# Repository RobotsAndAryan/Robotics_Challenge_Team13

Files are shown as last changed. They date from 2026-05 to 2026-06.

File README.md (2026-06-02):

# COMP0204 Term 3 Robotics Challenge (2025-2026) 
**Team Number:** 13
**Board ID:** Kayubo

Welcome to our Term 3 robotics project repository! This codebase contains our final firmware for the Trial #2 Checklist. 

For our navigation strategy, we quickly realized that just wandering around until the sensors hit a line wasn't going to work. The arena intersections all look exactly the same to the IR array. Instead, our robot uses a Finite State Machine (FSM) that counts the RFID tags and junctions as it passes them (`base_seq` and `arenaTagCount`). By keeping track of these "nodes", the robot basically knows its coordinates on the map and knows exactly when to turn or switch to dead-reckoning.

---

## Repository Structure
We separated our code into different files to keep the main loop clean and make it easier to debug specific parts of the hardware:

* `main.ino` - The main loop. It checks the network, handles the safety kill switches, and runs the main FSM.
* `config.h` - All our global variables, pin numbers, and PID/Motor speed limits.
* `motion.cpp / .h` - Handles the motor drivers, PWM voltage limits, and our IMU-assisted driving so it drives straight when off the line.
* `sensors.cpp / .h` - Reads the ToF sensor matrix and gets the pitch angle from the IMU.
* `nav.cpp / .h` - Holds the PID line follower logic and the wall-following code.
* `secrets.h` - (Not tracked in git) Contains our WiFi SSID/Passwords and MQTT IPs.
* `/docs` - Folder with Targets to attain, videos of robot's functions working and a report with evidence of sensor logging.
* `/tests` - Old scripts we used to unit-test each component by themselves before integrating them as well.

---

## Required Libraries & Hardware Setup
You'll need these libraries installed to compile our code:
* `Motoron` (Pololu Motoron M3S550 Shield) -> **I2C1**
* `Adafruit MPU6050` (IMU) -> **I2C1**
* `SparkFun VL53L5CX` (Time of Flight Imager) -> **I2C2**
* `MFRC522_I2C` (RFID Scanner) -> **I2C0**
* `Servo` -> **PWM**
* `MiniMessenger` -> **ESP32 WiFi Module**

### Hardware Wiring & Power Notes
* **Power:** We are using a 10.9V battery. To power the Arduino Giga R1 directly so the sensors don't lose power, we soldered a bridge between the `VM` and `AVIN` pins on the Motoron shield. 
* **Voltage Limits:** Our N20 motors are only rated for 6~7V. In `main.ino`, we cap the PWM at `440` (~6V) for normal driving, and bump it up to `514` (~7V) just for the ramp climb so we have enough torque.

---

## How to Run It

1. Clone this repo.
2. Create a `secrets.h` file next to the `.ino` file and put in your WiFi and MQTT credentials.
3. Open `main.ino` in the Arduino IDE (Board: Arduino Giga R1 WiFi) and upload it.
4. **IMU Calibration:** **DO NOT TOUCH THE ROBOT FOR 3 SECONDS AFTER TURNING IT ON.** The MPU6050 takes 200 samples to figure out its zero-bias. If you bump it, the dead-reckoning will curve.
5. **Running the Tasks:**
   * **Tasks 1-6 (Base to Arena):** Turn it on normally. It starts in safe mode. Press the button on `Pin 2` to arm the motors.
   * **Tasks 7 & 8 (Rescue/Obstacle):** Hold down the **Revival Button (Pin 46)** while you power on the board. The code skips the whole base sequence and goes straight into the rescue mode.

---

## System Diagrams & Flowcharts

### 1. Software & Hardware Architecture
We tried to keep the hardware reading separate from the motor writing. The sensors feed data to the control algorithms, which figure out the errors and send them to the FSM. The FSM then tells the motors what to do.

```mermaid
graph TD
    subgraph Hardware Layer
        ToF[VL53L5CX ToF]
        IMU[MPU6050]
        RFID[MFRC522]
        IR[9-Pin IR Array]
        MC[Motoron Controller]
        Srv[Seed Servo]
    end

    subgraph Core Software
        FSM[main.ino FSM Orchestrator]
        Nav[nav.cpp / motion.cpp]
        Net[MiniMessenger / MQTT]
    end

    ToF -->|Clearance Data| FSM
    IMU -->|Pitch Angle| Nav
    IR -->|Sensor Array Values| Nav
    RFID -->|Tag UID| FSM

    FSM <-->|MQTT Messages| Net
    Nav -->|PID Error Updates| FSM
    FSM -->|Motor Speeds| MC
    FSM -->|Servo Angles| Srv
```

### 2. Kill Switch & Emergency Handling
Safety is checked at the very start of the loop before any motor commands are allowed to run.

```mermaid
flowchart TD
    Start((Loop Start)) --> UI[updateUI]
    UI --> HardwareCheck{Pin 2 Pressed?}
    HardwareCheck -->|Yes| ToggleHW[Toggle physical_enable]
    HardwareCheck -->|No| NetCheck[Check MQTT]
    
    NetCheck --> ServerKill{Msg == disable?}
    ServerKill -->|Yes| ToggleNet[wifi_enable = false]
    
    ServerKill -->|No| ServerEmerg{Msg == emergency?}
    ServerEmerg -->|Yes| TriggerExit[Go to STATE_EXIT_SEQUENCE]
    
    ServerEmerg -->|No| Eval{physical & wifi enable = true?}
    
    ToggleHW --> Eval
    ToggleNet --> Eval
    TriggerExit --> Eval
    
    Eval -->|False| Stop[Stop Motors]
    Eval -->|True| FSM[Run Active FSM State]
    
    Stop --> End((Loop End))
    FSM --> End
```

### 3. FSM Routing Sequence (Trial #2)
This shows our exact route through the map, including skipping the first base tag and counting the arena tags to do the 1.25m maneuvers.

```mermaid
stateDiagram-v2
    direction TB
    
    [*] --> BootCheck

    state BootCheck <<choice>>
    BootCheck --> STATE_REVIVE_TARGET : Pin 46 Held
    BootCheck --> STATE_BASE_NAV : Normal Boot

    state STATE_BASE_NAV {
        direction TB
        state "seq=0: Junction 1" as seq0
        state "seq=1: Tag B Scanned" as seq1
        state "seq=2: Right Junction" as seq2
        state "seq=3: Ramp Approach" as seq3

        [*] --> seq0
        seq0 --> seq1 : Detect J1 -> Push & Turn Right (Skip Tag A)
        seq1 --> seq2 : Seed GPS -> Request Airlock A -> Push forward
        seq2 --> seq3 : Detect Right Branch -> Push & Turn Right
        seq3 --> [*] : Pitch < -10.0 deg
    }
    
    STATE_BASE_NAV --> STATE_RAMP_CLIMB

    state STATE_RAMP_CLIMB {
        [*] --> WallFollow
        WallFollow : 514 Speed, 7V Overvolt
        WallFollow --> [*] : Pitch > -5.0 deg
    }
    
    STATE_RAMP_CLIMB --> STATE_ARENA_NAV : Reached Flat Ground

    state STATE_ARENA_NAV {
        direction TB
        state LineFollow : PID Tracking
        state DeadReckon : Open Field Push (Task 4)
        state NodeDecision <<choice>>

        [*] --> LineFollow
        LineFollow --> DeadReckon : lostLineCount > 10
        DeadReckon --> LineFollow : Found Line Again
        LineFollow --> NodeDecision : RFID Tag Scanned
        
        NodeDecision --> LineFollow : tagCount = 1
        NodeDecision --> LineFollow : tagCount = 2 (Turn Right)
        NodeDecision --> LineFollow : tagCount = 3 (Turn Left)
    }

    STATE_ARENA_NAV --> STATE_WAIT_SERVER : Ask Server if Fertile
    STATE_WAIT_SERVER --> STATE_PLANT_SEED : isFertile = True & Seeds < 5
    STATE_WAIT_SERVER --> STATE_ARENA_NAV : isFertile = False OR Out of Seeds
    STATE_PLANT_SEED --> STATE_ARENA_NAV

    STATE_ARENA_NAV --> STATE_EXIT_SEQUENCE : currentXY == (9,3)
    STATE_EXIT_SEQUENCE --> STATE_EXIT_DRIVE : Calculate Turn Angle
    STATE_EXIT_DRIVE --> STATE_DOCKED : Airlock B Open
    STATE_DOCKED --> [*]
```

### 4. RFID Scanning & Planting Logic

```mermaid
flowchart TD
    Scan[readTagUID] --> CheckNew{Is it a new Tag?}
    CheckNew -->|No| Resume[Ignore and Keep Driving]
    CheckNew -->|Yes| Halt[Stop & Save UID]
    
    Halt --> Req[Send isFertile to Server]
    Req --> Wait[STATE_WAIT_SERVER]
    
    Wait --> Resp{Got Reply?}
    Resp -->|Timeout| Resume
    Resp -->|Yes| Fertile{isFertile == true?}
    
    Fertile -->|No| Resume
    Fertile -->|Yes| Plant[STATE_PLANT_SEED]
    
    Plant --> Servo[Move Servo & Wait]
    Servo --> Notify[Send seedPlanted Msg]
    Notify --> Resume
```

---

## Testing, Calibration & Bug Fixes
Getting the logic to match the physical real-world testing took a lot of trial and error. Here is what we calibrated and the main bugs we had to fix:

### Calibration
* **IR Sensor Thresholds:** We found that the ambient light in the lab read around ~400us on the floor and ~800us over the black tape. We set a hard cutoff at `500us` to filter out noise for our center-of-mass math.
* **PID Tuning:** We settled on `Kp = 20.0` and `Kd = 5.0` running at a base PWM of `440`. 
* **ToF Noise:** We had issues with the I2C bus getting overloaded when polling the ToF sensor too fast. We capped the ranging frequency to 60Hz and only read the middle horizontal band of pixels so a single bad reading wouldn't make the robot randomly stop.

### Major Bugs & How We Fixed Them
**1. Double scanning RFID**
* **What happened:** Whenever the motors vibrated over an RFID tag, the tag would bounce slightly out of range of the antenna and back in. The MFRC522 reader thought it was a new tag and would scan it twice in a row. This completely messed up our `arenaTagCount` and made the robot execute its grid turns way too early.
* **The fix:** We added a string comparison check (`strcmp`). We save the UID of the last tag we scanned, and if the "new" tag matches the previous one, the code just returns `false` and ignores it.

**2. Turning Too Early (Kinematic Overshoot)**
* **What happened:** Because our IR array is mounted at the very front of the chassis, it detects the T-Junctions before the wheels actually reach the intersection. When we triggered an immediate 90-degree turn, the robot would pivot off-center and completely lose the track.
* **The fix:** We hardcoded a tiny blind push (`moveForwardTicks(300)`) right before any 90-degree turn. This pulls the wheel axis directly over the center of the line before it pivots.

**3. Line lost in open field**
* **What happened:** If the robot lost the line, our old code would make it spin in place to try and find it again. This meant the robot couldn't handle the Open Field task, because it would just get stuck spinning in circles in the empty space.
* **The fix:** We changed the logic so that if the line is completely lost for more than 10 frames (`lostLineCount > 10`), it totally ignores the PID loop and just pushes straight ahead (`moveStraightDeadReckoning`) using the IMU gyro to keep its heading until it finds the line on the other side.

---

## Trial #2 Checklist
*This validates what our robot can actually do against the COMP0204 grading rubric.*

- [x] **1. Standard Line Tracking:** Smooth PID tracking using the 9-channel array.
- [x] **2. Intersection & Tag Alignment:** Navigates the base junctions, skips Tag B to save time, and stops over Tag A to request the airlock door(for now).
- [x] **3. Solid Grid Navigation:** Executes the exact 1.25m topological maneuver (Node 2 Right -> Node 3 Left) by counting tags.
- [x] **4. Open-Field Dead Reckoning:** Bridges unlined gaps by using the IMU to drive perfectly straight when the line disappears.
- [x] **5. Ramped Incline/Decline Control:** Uses the pitch angle to detect the ramp (`< -10.0` degrees) and increases motor PWM to climb it without stalling.
- [x] **6. Wall Following:** Uses LiDAR distance to keep a 130mm offset from the walls inside the airlocks.
- [x] **7. Obstacle Detection and Avoidance:** ToF sensor detects blocks, stops the robot, and traces a box around the obstacle, returning to its exact original heading.
- [x] **8. Touch-Based Robot Revival:** Uses distance data to smoothly slow down as it gets closer (`map` function from 150mm to 35mm), softly bumps the stranded robot, and reverses back onto the line.

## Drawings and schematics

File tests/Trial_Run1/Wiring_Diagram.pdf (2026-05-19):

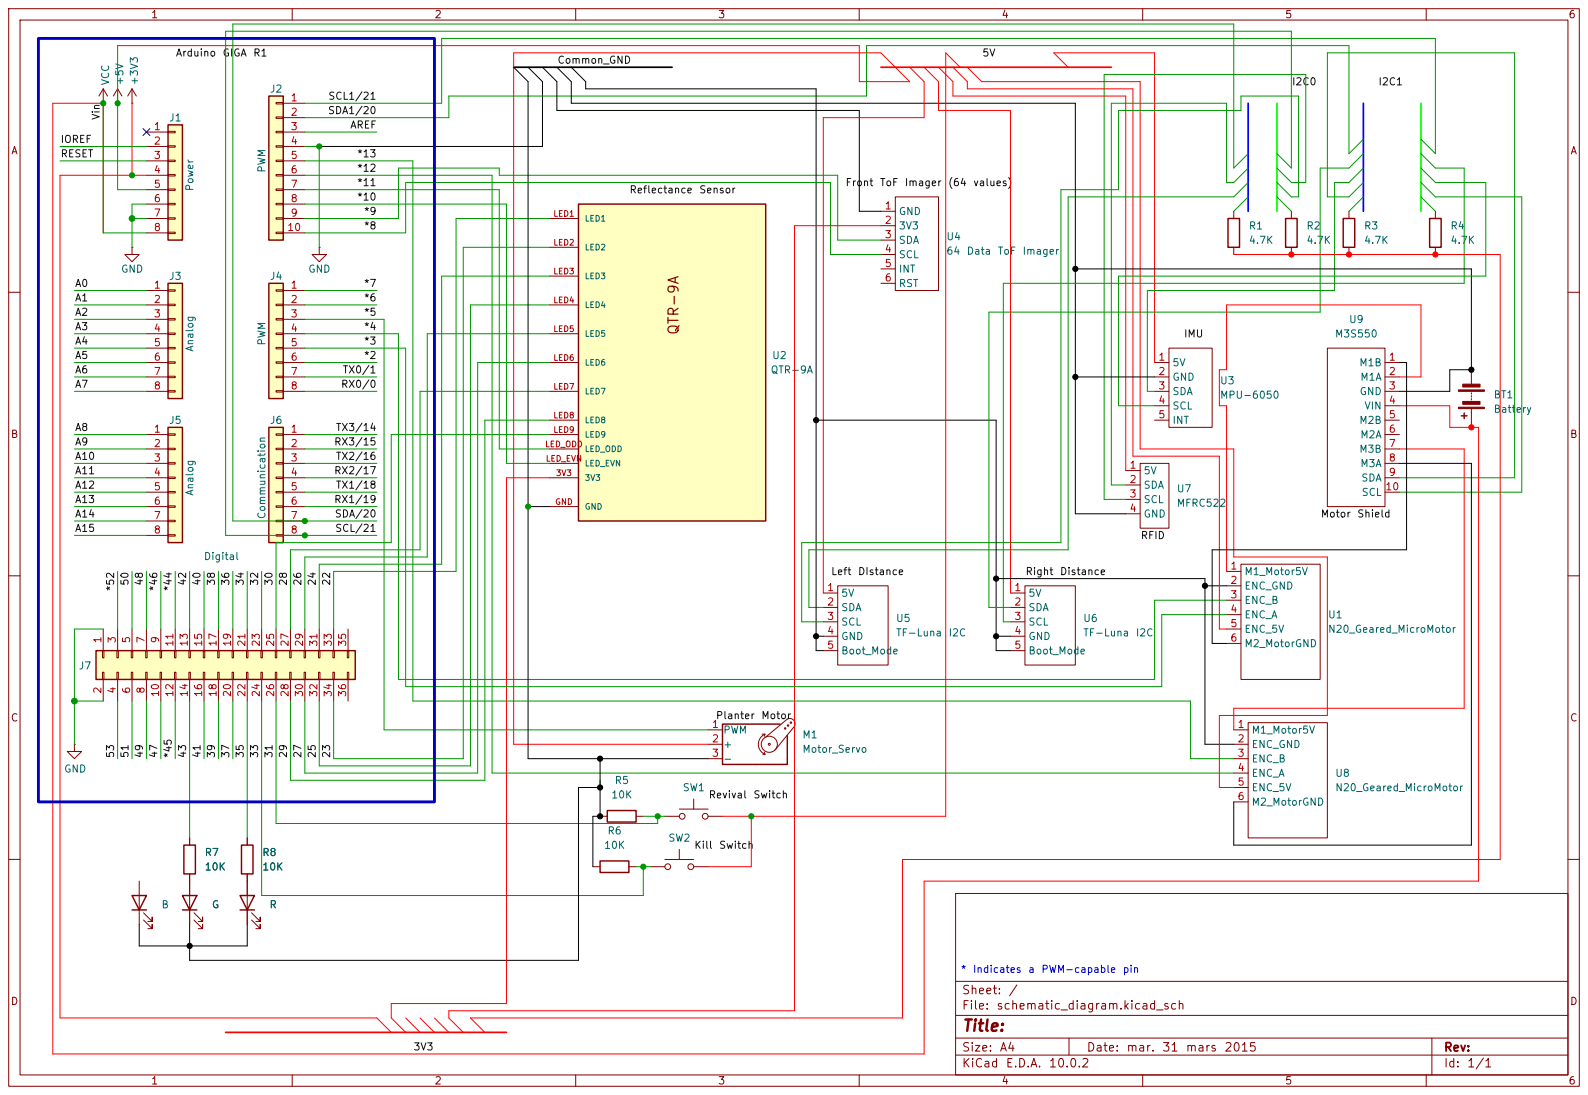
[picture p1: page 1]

SDA 3

64 Data ToF Imager GND LED3 LED3

LED4

Size: A4 | Rev:
KiCad E.D.A. 10.0.2 | Id: 1/1

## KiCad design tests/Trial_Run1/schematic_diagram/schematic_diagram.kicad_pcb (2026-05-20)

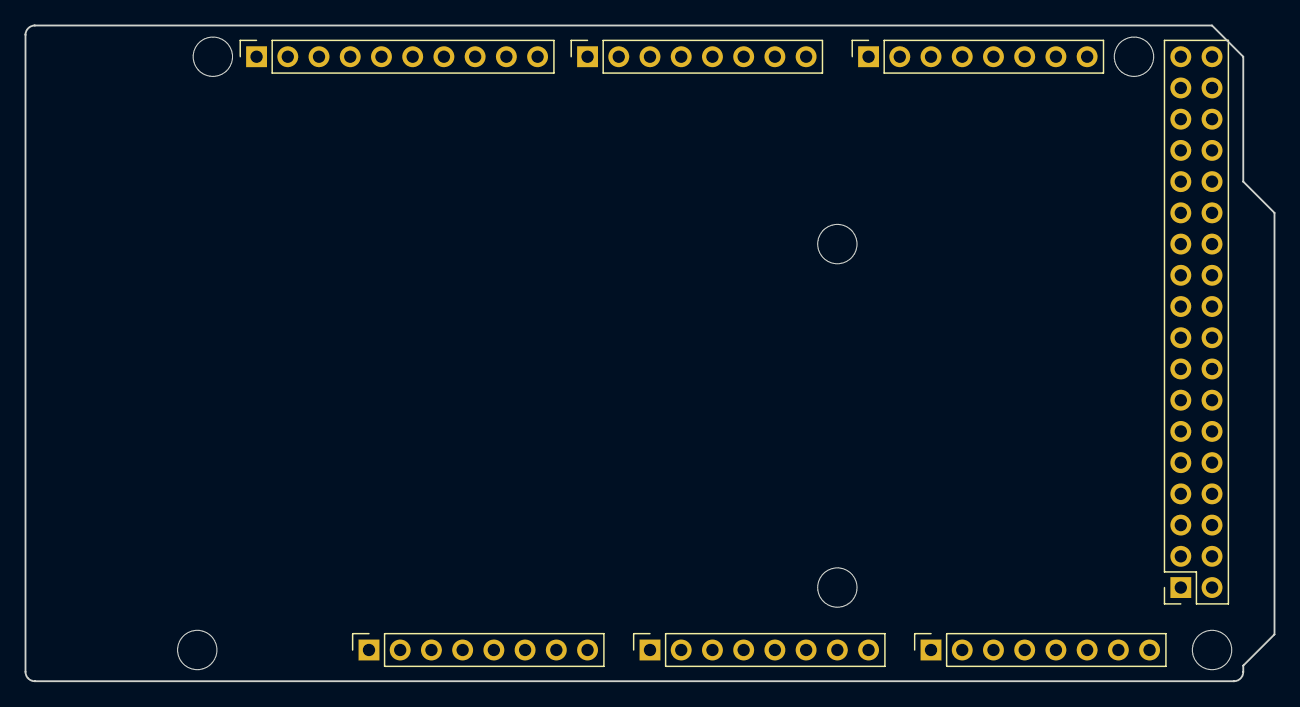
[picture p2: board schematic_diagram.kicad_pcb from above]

Board: 2 copper layers, 101.6 x 53.3 mm, 13 parts (0 on the bottom side), 4 nets, no tracks yet.

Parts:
J1: Power; PinSocket_1x08_P2.54mm_Vertical
J2: PWM; PinSocket_1x10_P2.54mm_Vertical
J3, J5: Analog; PinSocket_1x08_P2.54mm_Vertical
J4: PWM; PinSocket_1x08_P2.54mm_Vertical
J6: Communication; PinSocket_1x08_P2.54mm_Vertical
J7: Digital; PinSocket_2x18_P2.54mm_Vertical
MH1, MH2, MH3, MH4, MH5, MH6: MountingHole_3.2mm

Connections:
+5V: J1.5, J7.35, J7.36
/SCL/21: J2.1, J6.8
/SDA/20: J2.2, J6.7
GND: J1.6, J1.7, J2.4, J7.1, J7.2

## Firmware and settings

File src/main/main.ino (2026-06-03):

#include "config.h"
#include "motion.h"
#include "sensors.h"
#include "nav.h"
#include "secrets.h"

MotoronI2C mc;
Adafruit_MPU6050 imu;
SparkFun_VL53L5CX myToF;
MFRC522_I2C mfrc522(0x28, -1, &Wire); 
Servo seedServo;
MiniMessenger messenger;

const char* BoardId = "Kayubo";
const int LED_PIN = 4;
const int BUTTON_PIN = 2;
const int GREEN_LED_PIN = 3;
const int REVIVAL_BUTTON_PIN = 46;

volatile bool physical_enable = true;   
bool wifi_enable = false;      
bool pathBlocked = false;

volatile bool is_turning = false;

int enc1A = 44; int enc1B = 45;
int enc2A = 39; int enc2B = 40;
volatile long pos1 = 0; volatile long pos2 = 0;

int emitterOdd = 37; int emitterEven = 38;
int linePins[] = {22,23,24,25,26,27,28,29,30};
int weights[] = {40, 30, 20, 10, 0, -10, -20, -30, -40}; 

float Kp_line = 30.0; float Kd_line = 5.0; 
float Kp_wall = 50.0; float wall_target = 5.4; 
float Kp_heading = 30.0;                        
int baseSpeed_6V = 440; int baseSpeed_7V = 590; 
int turning_spd = 600; 
float lastError = 0;
int obstacleThreshold = 100; 
int lostLineCount = 0;
int currentServoAngle = 0;
float z_bias = 0.0;

float dr_targetYaw = 0.0;
float dr_currentYaw = 0.0;
unsigned long dr_lastIMUTime = 0;

RobotState currentState = START_STATE;
RobotState returnState = START_STATE; 
RobotState lastLoggedState = (RobotState)-1; 

unsigned long missionStartTime = 0;
bool missionActive = false;
const unsigned long ABORT_TIME_MS = 90000; 

int base_seq = 0;
int baseTagCount = 0;
int arenaTagCount = 0;
int seedsPlanted = 0;
const int MAX_SEEDS = 5;

bool entryCleared = false;
bool airlockCleared = false;
bool airlockBCleared = false;
bool waitingForServer = false;
bool isFertileZone = false;
unsigned long serverWaitStartTime = 0;
unsigned long flatGroundTime = 0;
char currentTag[32] = "";
char lastScannedTag[32] = ""; 

struct ArenaNode {
  char uid[32];
  int x;
  int y;
  bool known;
};
ArenaNode grid[81];
int currentX = -1;
int currentY = -1;
float globalHeading = 0.0; 

int pitchUpCount = 0;
int pitchDownCount = 0;

char logBuf[128]; 

const char* getStateName(RobotState state) {
  switch(state) {
    case STATE_BASE_NAV: return "BASE_NAV";
    case STATE_RAMP_CLIMB: return "RAMP_CLIMB";
    case STATE_RAMP_DECLINE: return "RAMP_DECLINE";
    case STATE_ARENA_NAV: return "ARENA_NAV";
    case STATE_WAIT_SERVER: return "WAIT_SERVER";
    case STATE_PLANT_SEED: return "PLANT_SEED";
    case STATE_OBSTACLE_AVOID: return "OBSTACLE_AVOID";
    case STATE_REVIVE_TARGET: return "REVIVE_TARGET";
    case STATE_DEAD_RECKONING: return "DEAD_RECKONING";
    case STATE_EXIT_SEQUENCE: return "EXIT_SEQUENCE";
    case STATE_EXIT_DRIVE: return "EXIT_DRIVE";
    case STATE_EXIT_WAIT_SERVER: return "EXIT_WAIT_SERVER";
    case STATE_AIRLOCK_WAIT_B: return "AIRLOCK_WAIT_B";
    case STATE_AIRLOCK_B_DECLINE: return "AIRLOCK_B_DECLINE";
    case STATE_DOCKED: return "DOCKED";
    case STATE_OBSTACLE_STOP : return "OBSTACLE STOPPED";
    default: return "UNKNOWN";
  }
}

void sysLog(const char* message) {
  Serial.println(message);
  if (wifi_enable) {
    messenger.sendToBoard("debug_console", message);
  }
}

void executeTurn(float targetAngle, bool turnLeft) {
  is_turning = true;
  turnAngle(targetAngle, turnLeft);
  is_turning = false;
}

void tick1() { if (digitalRead(enc1A) == digitalRead(enc1B)) pos1++; else pos1--; }
void tick2() { if (digitalRead(enc2A) == digitalRead(enc2B)) pos2++; else pos2--; }

bool robotEnabled() { return physical_enable && wifi_enable; }

bool isRightIntersection() {
  uint16_t lineVals[9];
  for(int i=0; i<9; i++) { pinMode(linePins[i], OUTPUT); digitalWrite(linePins[i], HIGH); }
  delayMicroseconds(15);
  for(int i=0; i<9; i++) { pinMode(linePins[i], INPUT); lineVals[i] = 1000; }
  
  unsigned long st = micros();
  while(micros() - st < 1000) {
    for(int i=0; i<9; i++) {
      if(lineVals[i] == 1000 && digitalRead(linePins[i]) == LOW) lineVals[i] = micros() - st;
    }
  }
  
  bool rightEdge = (lineVals[0] > 500 && lineVals[1] > 500 && lineVals[2] > 500);
  bool centerActive = (lineVals[3] > 500 || lineVals[4] > 500 || lineVals[5] > 500);
  bool leftClear = (lineVals[6] < 500 && lineVals[7] < 500);
  
  return (rightEdge && centerActive && leftClear);
}

bool isLeftIntersection() {
  uint16_t lineVals[9];
  for(int i=0; i<9; i++) { pinMode(linePins[i], OUTPUT); digitalWrite(linePins[i], HIGH); }
  delayMicroseconds(15);
  for(int i=0; i<9; i++) { pinMode(linePins[i], INPUT); lineVals[i] = 1000; }
  
  unsigned long st = micros();
  while(micros() - st < 1000) {
    for(int i=0; i<9; i++) {
      if(lineVals[i] == 1000 && digitalRead(linePins[i]) == LOW) lineVals[i] = micros() - st;
    }
  }
  
  bool leftEdge = (lineVals[6] > 500 && lineVals[7] > 500 && lineVals[8] > 500);
  bool centerActive = (lineVals[3] > 500 || lineVals[4] > 500 || lineVals[5] > 500);
  bool rightClear = (lineVals[0] < 500 && lineVals[1] < 500);
  
  return (leftEdge && centerActive && rightClear);
}

bool isTJunction() {
  uint16_t lineVals[9];
  for(int i=0; i<9; i++) { pinMode(linePins[i], OUTPUT); digitalWrite(linePins[i], HIGH); }
  delayMicroseconds(15);
  for(int i=0; i<9; i++) { pinMode(linePins[i], INPUT); lineVals[i] = 1000; }

  unsigned long st = micros();
  while(micros() - st < 1000) {
    for(int i=0; i<9; i++) {
      if(lineVals[i] == 1000 && digitalRead(linePins[i]) == LOW) lineVals[i] = micros() - st;
    }
  }

  bool leftEdge = (lineVals[6] > 500 && lineVals[7] > 500 && lineVals[8] > 500);
  bool rightEdge = (lineVals[0] > 500 && lineVals[1] > 500 && lineVals[2] > 500);
  bool centerActive = (lineVals[3] > 500 || lineVals[4] > 500 || lineVals[5] > 500);
  
  return (leftEdge && rightEdge && centerActive);
}

bool readTagUID() {
  if (mfrc522.PICC_IsNewCardPresent() && mfrc522.PICC_ReadCardSerial()) {
    char tempTag[32] = "";
    for (byte i = 0; i < mfrc522.uid.size; i++) {
      char hex[4]; snprintf(hex, sizeof(hex), "%02X", mfrc522.uid.uidByte[i]);
      strcat(tempTag, hex);
    }
    mfrc522.PICC_HaltA();

    if (strcmp(tempTag, lastScannedTag) == 0) {
      return false; 
    }
    
    stopMotors();
    strcpy(currentTag, tempTag);
    strcpy(lastScannedTag, currentTag);
    lastError = 0.0;
    lostLineCount = 0;
    
    snprintf(logBuf, sizeof(logBuf), "[RFID] %s", currentTag);
    sysLog(logBuf);
    return true;
  }
  return false;
}

void onMessage(const MessageMetadata& metadata, const uint8_t* payload, size_t length) {
  if (length == 0 || length == 6 || length == 21) return; 
  
  char msg[256];
  if (length >= sizeof(msg)) length = sizeof(msg) - 1;
  memcpy(msg, payload, length);
  msg[length] = '\0';

  if (strstr(msg, "type=heartbeat")) {
    if (strstr(msg, "enable=1") && !wifi_enable) {
      wifi_enable = true;
      sysLog("[NET] ENABLED");
    }
    else if (strstr(msg, "enable=0") && wifi_enable) {
      wifi_enable = false;
      sysLog("[NET] DISABLED");
    }
  }
  
  if (strstr(msg, "type=disable")) {
    wifi_enable = false;
    sysLog("[NET] KILL SWITCH TRIGGERED");
  }

  if (strstr(msg, "type=emergency")) {
    sysLog("[NET] EMERGENCY WARNING - RETURNING TO BASE");
    if (currentState != STATE_EXIT_SEQUENCE && currentState != STATE_EXIT_DRIVE &&
        currentState != STATE_EXIT_WAIT_SERVER && currentState != STATE_AIRLOCK_WAIT_B &&
        currentState != STATE_AIRLOCK_B_DECLINE && currentState != STATE_DOCKED) {
      lastScannedTag[0] = '\0'; 
      currentState = STATE_EXIT_SEQUENCE;
    }
  }
  
  if (currentState == STATE_BASE_NAV && strstr(msg, "entryReply") && strstr(msg, "accepted=true")) {
    entryCleared = true;
  }
  
  if (strstr(msg, "type=openAirlockReply") && strstr(msg, "accepted=true")) {
    if (strstr(msg, "airlock=A")) airlockCleared = true;
    if (strstr(msg, "airlock=B")) airlockBCleared = true;
  }
  
  if ((currentState == STATE_WAIT_SERVER || currentState == STATE_EXIT_WAIT_SERVER) && strstr(msg, "type=isFertileReply")) {
    isFertileZone = strstr(msg, "fertile=true") != nullptr;
    waitingForServer = false;
    
    char* yLoc = strstr(msg, "x=");
    char* xLoc = strstr(msg, "y=");
    if (xLoc && yLoc) {
      currentX = atoi(xLoc + 2);
      currentY = atoi(yLoc + 2);
      snprintf(logBuf, sizeof(logBuf), "[GPS] Updated: (%d, %d)", currentX, currentY);
      sysLog(logBuf);
      
      for(int i=0; i<81; i++) {
        if(!grid[i].known) {
          strcpy(grid[i].uid, currentTag);
          grid[i].x = currentX;
          grid[i].y = currentY;
          grid[i].known = true;
          break;
        } else if (strcmp(grid[i].uid, currentTag) == 0) {
          break;
        }
      }
    }
  }
}

void updateUI() {
  if (!is_turning) {
    messenger.loop();
  }

  static unsigned long lastBtn = 0;
  if (digitalRead(BUTTON_PIN) == LOW && millis() - lastBtn > 300) {
    physical_enable = !physical_enable;
    lastBtn = millis();
    snprintf(logBuf, sizeof(logBuf), "[HW] Switch Toggled: %s", physical_enable ? "ARMED" : "SAFE");
    sysLog(logBuf);
  }

  static unsigned long lastBlink = 0;
  static bool ledOn = false;
  digitalWrite(GREEN_LED_PIN, digitalRead(REVIVAL_BUTTON_PIN) == LOW ? HIGH : LOW);
  if (robotEnabled()) {
    digitalWrite(LED_PIN, HIGH);
  } else {
    if (millis() - lastBlink >= 500) {
      lastBlink = millis();
      ledOn = !ledOn;
      digitalWrite(LED_PIN, ledOn ? HIGH : LOW);
    }
  }

  static unsigned long lastReg = 0;
  if (millis() - lastReg > 3000) {
    char reg[64]; snprintf(reg, sizeof(reg), "type=register team_id=%s board_id=%s", GROUP_ID, BoardId);
    messenger.sendToBoard("server", reg);
    lastReg = millis();
  }
}

void normalizeHeading() {
  while(globalHeading >= 360.0) globalHeading -= 360.0;
  while(globalHeading < 0.0) globalHeading += 360.0;
}

void setup() {
  Serial.begin(115200);
  Wire.begin(); Wire1.begin(); Wire2.begin();

  sysLog("\n[BOOT] Initializing Hardware...");

  pinMode(emitterOdd, OUTPUT); pinMode(emitterEven, OUTPUT);
  digitalWrite(emitterOdd, HIGH); digitalWrite(emitterEven, HIGH);
  pinMode(LED_PIN, OUTPUT); 
  pinMode(BUTTON_PIN, INPUT_PULLUP);
  
  pinMode(GREEN_LED_PIN, OUTPUT); digitalWrite(GREEN_LED_PIN, LOW);
  pinMode(REVIVAL_BUTTON_PIN, INPUT_PULLUP);
  
  pinMode(enc1A, INPUT_PULLUP); pinMode(enc1B, INPUT_PULLUP);
  pinMode(enc2A, INPUT_PULLUP); pinMode(enc2B, INPUT_PULLUP);
  attachInterrupt(digitalPinToInterrupt(enc1A), tick1, CHANGE);
  attachInterrupt(digitalPinToInterrupt(enc2A), tick2, CHANGE);

  seedServo.attach(5); seedServo.write(0);

  mc.setBus(&Wire1); mc.setAddress(0x10);
  mc.reinitialize(); mc.clearResetFlag(); 
  mc.disableCommandTimeout(); 
  mc.setPwmMode(1, 6); mc.setPwmMode(3, 6);
  mfrc522.PCD_Init();

  if (imu.begin(0x68, &Wire1)) {
    imu.setGyroRange(MPU6050_RANGE_1000_DEG);
    float sum = 0;
    for(int i=0; i<100; i++) {
      sensors_event_t a, g, t; imu.getEvent(&a, &g, &t);
      sum += g.gyro.z; delay(2);
    }
    z_bias = sum / 100.0;
  }
  
  if (myToF.begin(0x29, Wire2)) { 
    myToF.setResolution(4 * 4); 
    myToF.setRangingFrequency(60); 
    myToF.startRanging(); 
  }
  
  for(int i=0; i<81; i++) grid[i].known = false;
  randomSeed(analogRead(0));
  messenger.onMessage(onMessage);
  messenger.begin(WIFI_SSID, WIFI_PASSWORD, BROKER_HOST, BROKER_PORT, GROUP_ID, BoardId);

  if (digitalRead(REVIVAL_BUTTON_PIN) == LOW) {
    currentState = STATE_REVIVE_TARGET;
    sysLog("[BOOT] MODE: TASK 8 (REVIVAL)");
  } else {
    currentState = STATE_EXIT_SEQUENCE;
    sysLog("[BOOT] MODE: TASKS 1-6 (FULL SEQUENCE)");
  }
}

void checkGlobalAbort() {
  if (missionActive && millis() - missionStartTime > ABORT_TIME_MS &&
      currentState != STATE_EXIT_SEQUENCE && currentState != STATE_EXIT_DRIVE &&
      currentState != STATE_EXIT_WAIT_SERVER && currentState != STATE_AIRLOCK_WAIT_B &&
      currentState != STATE_AIRLOCK_B_DECLINE && currentState != STATE_DOCKED) {
    sysLog("[MISSION] TIMEOUT. ABORTING.");
    lastScannedTag[0] = '\0';
    currentState = STATE_EXIT_SEQUENCE;
  }
}

void loop() {
  updateUI();

  if (robotEnabled() && !missionActive) {
    missionStartTime = millis();
    missionActive = true;
    sysLog("[MISSION] Timer Started.");
  }

  if (currentState != lastLoggedState) {
    snprintf(logBuf, sizeof(logBuf), "[FSM] %s", getStateName(currentState));
    sysLog(logBuf);
    lastLoggedState = currentState;
  }

  if (!robotEnabled()) { stopMotors(); delay(5); return; }

  checkGlobalAbort();

 // FIX: Explicitly separate the Stop logic (Base) from the Bypass logic (Arena)
  if (currentState == STATE_ARENA_NAV) {
      checkFrontObstacle();
      if (pathBlocked) {
          stopMotors();
          sysLog("[EVENT] Obstacle Detected - Stopping till clear");
          returnState = currentState; 
          currentState = STATE_OBSTACLE_AVOID;
          return;
      }
  } 
  else {
      checkFrontObstacle();
      if (pathBlocked) {
          stopMotors();
          sysLog("[EVENT] Obstacle Detected - Engaging FSM Bypass");
          returnState = currentState; 
          currentState = STATE_OBSTACLE_STOP;
          return;
      }
  }

  float pitch = getPitch();

  switch (currentState) {
    case STATE_BASE_NAV: {
      int navSpeed = (base_seq == 1 || base_seq == 3) ? baseSpeed_6V / 1.1 : baseSpeed_6V;
      int navMax = (base_seq == 1 || base_seq == 3) ? 440 : 500;
      
      if (!executeLineFollow(navSpeed, navMax)) {
        if(++lostLineCount > 25) {
          stopMotors();
          if (base_seq == 3) {
            sysLog("[NAV] Track gap. Pushing blind toward ramp.");
            moveStraightDeadReckoning(300); 
          } else {
            sysLog("[NAV] Track gap recovery push.");
            moveForwardTicks(400); 
          }
          lostLineCount = 0;
        }
      } else {
        lostLineCount = 0;
        long currentDist = (abs(pos1) + abs(pos2)) / 2;
        
        if (base_seq == 0 && currentDist > 500 && isTJunction()) {
          stopMotors();
          sysLog("[NAV] Junc 1: Aligning & Turning Right");
          moveForwardTicks(450); 
          executeTurn(90.0, false);
          base_seq = 1;
          pos1 = 0; pos2 = 0;
        }
        else if (base_seq == 2 && currentDist > 800 && (isTJunction() || isRightIntersection())) {
          stopMotors();
          sysLog("[NAV] Junc 2: Aligning & Turning Right again");
          moveForwardTicks(450); 
          executeTurn(90.0, false); 
          base_seq = 3;
          pos1 = 0; pos2 = 0;
        }
      }

      if (base_seq == 1 && readTagUID()) {
        sysLog("[EVENT] Tag Scanned. Requesting Airlock A.");
        char query[128]; snprintf(query, sizeof(query), "type=openAirlock airlock=A tag_id=%s board_id=%s", currentTag, BoardId);
        messenger.sendToBoard("server", query);
        airlockCleared = false;
        {
          unsigned long airlockWaitStart = millis();
          while(!airlockCleared && millis() - airlockWaitStart < 5000) {
            updateUI(); delay(10);
            if(!robotEnabled()) return;
          }
        }
        sysLog("[NAV] Airlock Open. Pushing through.");
        moveForwardTicks(800);
        base_seq = 2; 
        pos1 = 0; pos2 = 0;
      }

      if (base_seq == 3) {
        if (pitch < -5.0) {
          pitchUpCount++;
          if (pitchUpCount > 5) {
            sysLog("[NAV] Ramp incline confirmed.");
            currentState = STATE_RAMP_CLIMB;
            pitchDownCount = 0;
            flatGroundTime = 0;
          }
        } else {
          pitchUpCount = 0;
        }
      }
      break;
    }

    case STATE_RAMP_CLIMB:
          if (!executeWallFollow(baseSpeed_7V, 800, 1)) {
            setMotors(baseSpeed_7V, baseSpeed_7V, 800); 
          }
          if (abs(pitch) < 5.0) {
            if (flatGroundTime == 0) flatGroundTime = millis();
            else if (millis() - flatGroundTime > 100) {
              sysLog("[NAV] Ramp cleared. Entering Arena.");
              currentState = STATE_ARENA_NAV;
            }
          } else flatGroundTime = 0;
      break;

    case STATE_RAMP_DECLINE:
      if (!executeWallFollow(baseSpeed_6V/1.2, 440, 3)) {
        setMotors(baseSpeed_6V/1.2, baseSpeed_6V/1.2, 440);
      }
      if (abs(pitch) < 5.0) {
        if (flatGroundTime == 0) flatGroundTime = millis();
        else if (millis() - flatGroundTime > 400) {
          currentState = STATE_ARENA_NAV;
        }
      } else flatGroundTime = 0;
      break;

    case STATE_ARENA_NAV: {
      if (!executeLineFollow(baseSpeed_6V, 440)) {
        if(++lostLineCount > 15) {
          stopMotors();
          sysLog("[NAV] Line Lost. Transitioning to FSM Dead Reckoning.");
          dr_targetYaw = globalHeading; 
          dr_currentYaw = globalHeading;
          dr_lastIMUTime = micros();
          currentState = STATE_DEAD_RECKONING;
          lostLineCount = 0;
        }
      } else lostLineCount = 0;

      if (readTagUID()) {
        arenaTagCount++;

        if (arenaTagCount == 1) {
          currentX = 9; currentY = 3;
          snprintf(logBuf, sizeof(logBuf), "[GPS] Entry Node Seeded at (%d, %d)", currentX, currentY);
          sysLog(logBuf);
        }

        waitingForServer = true;
        serverWaitStartTime = millis();
        currentState = STATE_WAIT_SERVER;

        char query[128]; snprintf(query, sizeof(query), "type=isFertile tag_id=%s board_id=%s", currentTag, BoardId);
        messenger.sendToBoard("server", query);

        if (arenaTagCount == 3) {
            sysLog("[NAV] Task 3: Turn Right at Node 3.");
            executeTurn(90.0, false);
            globalHeading -= 90.0;
            normalizeHeading();
        } else if (arenaTagCount == 4) {
            sysLog("[NAV] Task 3: Turn Left at Node 4.");
            executeTurn(90.0, true);
            globalHeading += 90.0;
            normalizeHeading();
        }
      }
      break;
    }

    case STATE_DEAD_RECKONING: {
      sensors_event_t a, g, t;
      imu.getEvent(&a, &g, &t);
      unsigned long now = micros();
      if(dr_lastIMUTime == 0) dr_lastIMUTime = now;
      float dt = (now - dr_lastIMUTime) / 1000000.0;
      dr_lastIMUTime = now;

      float gyroZ = (g.gyro.z - z_bias) * 57.2958;
      if(abs(gyroZ) > 1.0) dr_currentYaw -= gyroZ * dt; 

      float headingError = dr_targetYaw - dr_currentYaw;
      float correction = Kp_heading * headingError;

      setMotors(baseSpeed_6V - correction, baseSpeed_6V + correction, 440);

      if (isLineDetected()) {
        stopMotors();
        sysLog("[NAV] Track re-acquired.");
        dr_lastIMUTime = 0;
        currentState = STATE_ARENA_NAV;
      }
      else if (readTagUID()) {
        stopMotors();
        dr_lastIMUTime = 0;
        arenaTagCount++;
        waitingForServer = true;
        serverWaitStartTime = millis();
        currentState = STATE_WAIT_SERVER;
        
        char query[128]; snprintf(query, sizeof(query), "type=isFertile tag_id=%s board_id=%s", currentTag, BoardId);
        messenger.sendToBoard("server", query);

        if (arenaTagCount == 3) {
            sysLog("[NAV] Task 4: Turn Right at Node 3.");
            executeTurn(90.0, false);
            globalHeading -= 90.0;
            normalizeHeading();
        } else if (arenaTagCount == 4) {
            sysLog("[NAV] Task 4: Turn Left at Node 4.");
            executeTurn(90.0, true);
            globalHeading += 90.0;
            normalizeHeading();
        }
      }
      break;
    }

    case STATE_WAIT_SERVER:
      stopMotors();
      if (!waitingForServer) {
        if (isFertileZone && seedsPlanted < MAX_SEEDS) {
          currentState = STATE_PLANT_SEED;
        } else {
          if (isFertileZone && seedsPlanted >= MAX_SEEDS) sysLog("[WARN] Seeds exhausted. Skipping plant.");
          if (!isLineDetected()) {
            dr_targetYaw = globalHeading;
            dr_currentYaw = globalHeading;
            dr_lastIMUTime = micros();
            currentState = STATE_DEAD_RECKONING;
          } else {
            currentState = STATE_ARENA_NAV;
          }
        }
      } else if (millis() - serverWaitStartTime > 5000) {
        sysLog("[ERROR] Server Timeout.");
        if (!isLineDetected()) {
            dr_targetYaw = globalHeading;
            dr_currentYaw = globalHeading;
            dr_lastIMUTime = micros();
            currentState = STATE_DEAD_RECKONING;
        } else {
            currentState = STATE_ARENA_NAV;
        }
      }
      break;

    case STATE_PLANT_SEED:
      snprintf(logBuf, sizeof(logBuf), "[ACTION] Planting Seed %d/%d.", seedsPlanted + 1, MAX_SEEDS);
      sysLog(logBuf);
      moveForwardTicks(640);
      stopMotors();
      delay(500);
      {
        int targetAngle = currentServoAngle + 45;
        if(targetAngle > 180) targetAngle = 180;
        while(currentServoAngle < targetAngle) {
          currentServoAngle += 2;
          if(currentServoAngle > targetAngle) currentServoAngle = targetAngle;
          seedServo.write(currentServoAngle);
          delay(30);
        }
      }
      for(int d=0; d<10; d++) { delay(100); updateUI(); }
      seedsPlanted++;

      {
        char notify[128]; snprintf(notify, sizeof(notify), "type=seedPlanted tag_id=%s board_id=%s", currentTag, BoardId);
        messenger.sendToBoard("server", notify);
      }
      lastError = 0;
      if (!isLineDetected()) {
          dr_targetYaw = globalHeading;
          dr_currentYaw = globalHeading;
          dr_lastIMUTime = micros();
          currentState = STATE_DEAD_RECKONING;
      } else {
          currentState = STATE_ARENA_NAV;
      }
      break;
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

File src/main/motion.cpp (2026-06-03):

#include "config.h"
#include "motion.h"
#include "sensors.h"
#include "nav.h"
#include <Arduino.h>

void setMotors(int l, int r, int max_pwm) {
  if(l > max_pwm) l = max_pwm;
  if(l < -max_pwm) l = -max_pwm;
  if(r > max_pwm) r = max_pwm;
  if(r < -max_pwm) r = -max_pwm;
  mc.setSpeed(1, -l);
  mc.setSpeed(3, -r);
}

void stopMotors() {
  setMotors(0, 0, 800);
}

void turnAngle(float targetAngle, bool turnLeft) {
  stopMotors();
  unsigned long dStart = millis();
  while(millis() - dStart < 300) { updateUI(); if(!robotEnabled()) return; delay(1); }

  float currentYaw = 0;
  unsigned long lastIMUTime = micros();
  int lSpeed = turnLeft ? -turning_spd : turning_spd;
  int rSpeed = turnLeft ? turning_spd : -turning_spd;

  setMotors(lSpeed, rSpeed, 800);
  float actualTarget = targetAngle - 4.0;
  unsigned long turnStart = millis();

  while(abs(currentYaw) < actualTarget) {
    updateUI(); 
    if(!robotEnabled()) { stopMotors(); return; }
    if(millis() - turnStart > 4000) { break; }

    sensors_event_t a, g, t;
    imu.getEvent(&a, &g, &t);
    unsigned long now = micros();
    float dt = (now - lastIMUTime) / 1000000.0;
    lastIMUTime = now;
    
    float gyroZ = (g.gyro.z - z_bias) * 57.2958;
    if(abs(gyroZ) > 1.0) currentYaw += gyroZ * dt; 
  }

  stopMotors();
  dStart = millis();
  while(millis() - dStart < 300) { updateUI(); if(!robotEnabled()) return; delay(1); }
  lastError = 0;
}

void moveForwardTicks(long targetTicks) {
  pos1 = 0; pos2 = 0;
  unsigned long moveStart = millis();
  setMotors(baseSpeed_6V, baseSpeed_6V, 440);
  while(abs(pos1) < targetTicks && abs(pos2) < targetTicks) {
    updateUI();
    if(!robotEnabled()) { stopMotors(); return; }
    if(millis() - moveStart > 5000) { break; }
    delay(1);
  }
  stopMotors();
}

void moveStraightDeadReckoning(long targetTicks) {
  pos1 = 0; pos2 = 0;
  float currentYaw = 0;
  unsigned long lastIMUTime = micros();
  unsigned long moveStart = millis();

  while(abs(pos1) < targetTicks && abs(pos2) < targetTicks) {
    updateUI();
    if(!robotEnabled()) { stopMotors(); return; }
    if(millis() - moveStart > 5000) { break; }

    checkFrontObstacle();
    if(pathBlocked) { stopMotors(); return; }

    sensors_event_t a, g, t;
    imu.getEvent(&a, &g, &t);
    unsigned long now = micros();
    float dt = (now - lastIMUTime) / 1000000.0;
    lastIMUTime = now;

    float gyroZ = (g.gyro.z - z_bias) * 57.2958;
    if(abs(gyroZ) > 1.0) currentYaw -= gyroZ * dt;

    float headingError = 0.0 - currentYaw;
    float correction = Kp_heading * headingError;

    setMotors(baseSpeed_6V - correction, baseSpeed_6V + correction, 440);
    delay(2);
  }
  stopMotors();
}

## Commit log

2026-04-28 correcting IR test code
    [reflectance.ino]
2026-05-05 Tested the Wall Lidar
2026-05-06 IMU sensor code working
2026-05-06 PID in Line Following
2026-05-09 motor testing code added
2026-05-09 Added wiring details on the newly created first main code
2026-05-13 Trial Run 1 Code
    [schematic_diagram.kicad_pcb, schematic_diagram.kicad_sch]
2026-05-14 Fixed? Trial Run 1 Code
    [Trial_Run_Code.ino]
2026-05-19 Create ArduinoComms
2026-05-19 working code
    [schematic_diagram.kicad_sch]
2026-05-19 Add files via upload
    Kill switch code so far
2026-05-20 new Line Following and front object detection
    [schematic_diagram.kicad_pcb]
2026-05-21 Add files via upload
    Latest working code for kill switch - wifi and physical
2026-05-21 Create rfid_servo_linefollowing
    Current codebase at 16:12 21/05 subject to change.
2026-05-21 Create ServoTestCode
2026-05-21 Servo fixed(hopefully)
2026-05-26 Changed ANTEST1 to have revival button and all the inetrgating code a bit more corrected
    [ANtest1.ino, Line_Wall_RFID_Servo_4.ino, Line_Wall_RFID_Servo_Wifi_Stages_5.ino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]
2026-05-26 fixed wall following target distance to appropriate units
    [Line_Wall_RFID_Servo_4.ino]
2026-05-26 Edited Modular code to reflect new fixes
    [main.ino, motion.cpp, nav.cpp]
2026-05-26 edited modular code a bit for fixes0
    [main.ino]
2026-05-27 fixed led and button
    [ANtest1.ino, main.ino, motion.cpp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]
2026-05-27 fixed revival motor speeds
    [main.ino]
2026-05-27 Added Obstacle avoidance and interrupt
    [main.ino, motion.cpp, nav.cpp]
2026-05-27 fixed obstacle avoidance a bit
    [main.ino]
2026-05-28 base navigation ig fixed? , needs to be tested again
    [main.ino]
2026-05-29 fixed for the last intersection in base
    [main.ino, nav.cpp]
2026-05-29 old flowchard order removed
2026-05-29 fixed src folder roots
    [main.ino, motion.cpp, nav.cpp]
2026-06-02 fixed base navigation (testing required)
    [main.ino, motion.cpp, nav.cpp]
2026-06-02 fixed nav logic (requires testing)
    [main.ino]
2026-06-02 Obstacle Avoidance uses encoders for re-alignment(testing required)
    [main.ino]
2026-06-02 fixed wall following sign changed(needs testing)
    [main.ino, motion.cpp, nav.cpp]
2026-06-02 fixed ramp transition (testing req)
    [main.ino, nav.cpp]
2026-06-02 sequential obstacle avoidance improved
    [main.ino]
2026-06-03 working base+ramp, needs arena entrance fixing
    [main.ino, motion.cpp, nav.cpp]
2026-06-03 possible arena entry fix
    [main.ino]
2026-06-03 Revert "working base+ramp+arena entry final"
    This reverts commit 79be7f12ec87a2fabaf9c834477b16a023fb7c46.
    Broken junction logic , so reverting to older code with correct one
    [main.ino]
